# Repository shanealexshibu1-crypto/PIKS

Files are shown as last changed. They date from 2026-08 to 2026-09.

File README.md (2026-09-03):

# PIXS

Pixs is a 6 legged hexapod with 3-dof per leg i.e a hexapod with 18-dof. Custom made with a final volume box of 32 cm x 19.2 xm x 29.1 cm

## Printing Parts

Material used is PET-G

| Setting |  value |
| --- | ---: |
| **Nozzle** | **240°C** |
| **Bed** | **80°C** |
| **Part cooling** | **30–50%** |
| **Print speed** | **40–60 mm/s** |
| **First-layer nozzle** | **245°C** |
| **First-layer bed** | **80°C** |
| **Infill** | **10-15%** |

Do not print anything from the Assembly CAD section it is for reference only

## Assembly

1. Print 6 copies of Coxa Link 1_Part1, Coxa link 1_Part 2, Coxa Link 2_Part 1, Coxa Link 2_Part 2, Femur Part 1, Femur Part 2, Tibia, Servo Mount Coxa Bottom, Servo Mount Coxa Middle
   ,Servo Mount Coxa Top, Servo Mount Femur Bottom, Servo Mount Femur Middle,Servo Mount Femur Top, Servo Mount Tibia Bottom, Servo Mount Tibia Middle, Servo Mount Tibia Top.
   
2. Print 1 copy of Body Base and Body Top.

3. Insert One 606zz Ball Bearings into all 18 bottom of the servo mounts.

4. Then attach the Middle and top attachments of the Servo Mount. Secure this with 4pcs 45mm m3 Screw and heated inserts

5. Attach the Servo Horns that come with the Servo to all the servos.

6. Combine Coxa Link 1_Part 1 , Coxa Link 1_Part 2 and Coxa Servo Joint. Secure this with 3 pcs of m3 x 10mm screws and heated inserts.Repeat this 6 times.

7. Combine Coxa Link 2_Part 1, Coxa Link 2_Part 2 and Femur Servo Joint. Secure this with 3pcs of m3 x 10mm Screwa and heated inserts. Repeat this 6 times.

8. Combine the products from step 6 and step 7  using 5 pcs of m3x15mm Screws and heated inserts.Repeat this 6 times.

9. Attach the Femur Part 1 , femur Part 2, Tibia servo joint with m3 x 10mm screws and heated inserts.Repeat 6 times.

10. combine the femur with the product from step 8 with m3 x 10mm screws and heated inserts.Repeat 6 times.

11. finally cominbe the tibia and the product from step 10 with m3x10mm screws.Repeat 6 times.

12. Now you have finished 6 legs.

13. Next take the legs and secure them in the designated spots with m3 x 10 mm screws. Repeat this 6 times.

14. Then finish the design with the top plate with m3 x 10 mm screws and heated inserts.

15. Now u have a finished Assembled hexapod.

## Circuit Diagram

Screenshot 2026-09-01 at 8 35 06 PM

## Gallery

### One of the Finished Servo Mount

Screenshot 2026-09-01 at 5 22 45 PM

### Finished Leg Side View

Screenshot 2026-09-01 at 5 24 09 PM

### Base Plate(Body)

Screenshot 2026-09-01 at 5 28 04 PM

### Fully assembled Hexapod(Front View)

Screenshot 2026-09-01 at 5 33 56 PM

### Fully assembled Hexapod(Side View)

Screenshot 2026-09-01 at 5 34 15 PM

### Fully assembled Hexapod(Top View)

Screenshot 2026-09-01 at 5 34 48 PM

## Firmware 

### Features:

1. The firmware uses a tripod gait that follows the bezier curve.
2. Uses a 3rd party PS2 style controller to control the Hexapod, Left joystick for movement and right joystick for rotation and height adjustment.

### Installation

  1.Download the latest version of Arduino IDE
  
  2.Download the firmware from my github repo.
  
  3.Open the firmware with Arduino IDE.
  
  4.Connect the Arduino Mega to the laptop via Usb Cable.
  
  5.Finally, verify and upload the code to the Mega.
  
  6.Enjoy a fully working Hexapod.

## BOM

|Part Name |Qty|Pcs per Qty|Cost (AED)|Purchase Place|Purchase Link|
|---|---|---|---|---|---|
|Breadboard |1  |1 |2.68 |Ali Express |[Link](https://ar.aliexpress.com/item/1005009010052772.html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) |
|LiPo Battery |1  |1 |79.11 |Ali Express |[Link](https://ar.aliexpress.com/item/1005011908692707.html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) |
|M3 Screw 15mm |15 |10 |3.69 |Ali Express |[Link](https://ar.aliexpress.com/item/1005008693358029.html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) |
|M3 Screw 10mm |20 |10 |3.36 |Ali Express |[Link](https://ar.aliexpress.com/item/1005008693358029.html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) |
|Jumper Wires |1  |1 |12.39 |Ali Express |[Link](https://ar.aliexpress.com/item/1005012273851640.html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) |
|Capacitors 6.3 V (1000 uF)|1  |20 |9.7 |Ali Express |[Link](https://ar.aliexpress.com/item/1005006186858370.html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) |
|LED Toggle Switch |1  |1 |27.03 |Ali Express |[Link](https://ar.aliexpress.com/item/1005008856506094.html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) |
|Servo Extentions |1  |15 |26.42 |Ali Express |[Link](https://ar.aliexpress.com/item/1005010660995814.html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) |
|5V 15A Regulator |1  |1 |50.39 |Ali Express |[Link](https://ar.aliexpress.com/item/1005010218924050.html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) |
|DIN7991 M3 × 45mm Bolts |1  |50 |25.47 |Ali Express |[Link](https://ar.aliexpress.com/item/1005012615504199.html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) |
|DIN7991 M3 × 45mm Bolts |1  |50 |25.29 |Ali Express |[Link](https://ar.aliexpress.com/item/1005012779784744.html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) |
|PCA9685 Servo Driver |1  |2 |26.83 |Ali Express |[Link](https://ar.aliexpress.com/item/1005008717177681.html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) |
|Wireless Controller |1  |1 |42.2 |Ali Express |[Link](https://ar.aliexpress.com/item/1005012464305134.html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) |
|MEGA2560 R3 |1  |1 |61.57 |Ali Express |[Link](https://ar.aliexpress.com/item/1005008973924627.html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) |
|MG996 Servo |18 |1 |16.31 |Ali Express |[Link](https://ar.aliexpress.com/item/1005001878275044.html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) |
|Ball Bearing |2  |10 |28 |Ali Express |[Link](https://ar.aliexpress.com/item/560944845.html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) |
|Heated inserts |4  |100 |16.96 |Ali Express |[Link](https://ar.aliexpress.com/item/1005006201944599.html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) |
| | | | | | |
| | |TOTAL: |457.4 AED | | |

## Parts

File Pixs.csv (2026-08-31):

Part Name | Qty | Pcs per Qty | Cost (AED) | Purchase Place | Purchase Link
Breadboard | 1 | 1 | 2.68 | Ali Express | Link
LiPo Battery | 1 | 1 | 79.11 | Ali Express | Link
M3 Screw 15mm | 15 | 10 | 3.69 | Ali Express | Link
M3 Screw 10mm | 20 | 10 | 3.36 | Ali Express | Link
Jumper Wires | 1 | 1 | 12.39 | Ali Express | Link
Capacitors 6.3 V (1000 uF) | 1 | 20 | 9.7 | Ali Express | Link
LED Toggle Switch | 1 | 1 | 27.03 | Ali Express | Link
Servo Extentions | 1 | 15 | 26.42 | Ali Express | Link
5V 15A Regulator | 1 | 1 | 50.39 | Ali Express | Link
DIN7991 M3 × 45mm Bolts | 1 | 50 | 25.47 | Ali Express | Link
DIN7991 M3 × 45mm Bolts | 1 | 50 | 25.29 | Ali Express | Link
PCA9685 Servo Driver | 1 | 2 | 26.83 | Ali Express | Link
Wireless Controller | 1 | 1 | 42.2 | Ali Express | Link
MEGA2560 R3 | 1 | 1 | 61.57 | Ali Express | Link
MG996 Servo | 18 | 1 | 16.31 | Ali Express | Link
Ball Bearing | 2 | 10 | 28 | Ali Express | Link
Heated inserts | 4 | 100 | 16.96 | Ali Express | Link
 |  | TOTAL: | 457.4 AED

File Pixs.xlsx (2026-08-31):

Part Name | Qty | Pcs per Qty | Cost (AED) | Purchase Place | Purchase Link
Breadboard | 1 | 1 | 2.68 | Ali Express | Link (https://ar.aliexpress.com/item/1005009010052772.html?mp=1)
LiPo Battery | 1 | 1 | 79.11 | Ali Express | Link (https://ar.aliexpress.com/item/1005011908692707.html?mp=1)
M3 Screw 15mm | 15 | 10 | 3.69 | Ali Express | Link (https://ar.aliexpress.com/item/1005008693358029.html?mp=1)
M3 Screw 10mm | 20 | 10 | 3.36 | Ali Express | Link (https://ar.aliexpress.com/item/1005008693358029.html?mp=1)
Jumper Wires | 1 | 1 | 12.39 | Ali Express | Link (https://ar.aliexpress.com/item/1005012273851640.html?mp=1)
Capacitors 6.3 V (1000 uF) | 1 | 20 | 9.7 | Ali Express | Link (https://ar.aliexpress.com/item/1005006186858370.html?mp=1)
LED Toggle Switch | 1 | 1 | 27.03 | Ali Express | Link (https://ar.aliexpress.com/item/1005008856506094.html?mp=1)
Servo Extentions | 1 | 15 | 26.42 | Ali Express | Link (https://ar.aliexpress.com/item/1005010660995814.html?mp=1)
5V 15A Regulator | 1 | 1 | 50.39 | Ali Express | Link (https://ar.aliexpress.com/item/1005010218924050.html?mp=1)
DIN7991 M3 × 45mm Bolts | 1 | 50 | 25.47 | Ali Express | Link (https://ar.aliexpress.com/item/1005012615504199.html?mp=1)
DIN7991 M3 × 45mm Bolts | 1 | 50 | 25.29 | Ali Express | Link (https://ar.aliexpress.com/item/1005012779784744.html?mp=1)
PCA9685 Servo Driver | 1 | 2 | 26.83 | Ali Express | Link (https://ar.aliexpress.com/item/1005008717177681.html?mp=1)
Wireless Controller | 1 | 1 | 42.2 | Ali Express | Link (https://ar.aliexpress.com/item/1005012464305134.html?mp=1)
MEGA2560 R3 | 1 | 1 | 61.57 | Ali Express | Link (https://ar.aliexpress.com/item/1005008973924627.html?mp=1)
MG996 Servo | 18 | 1 | 16.31 | Ali Express | Link (https://ar.aliexpress.com/item/1005001878275044.html?mp=1)
Ball Bearing | 2 | 10 | 28 | Ali Express | Link (https://ar.aliexpress.com/item/560944845.html?curPageLogUid=WHP7pWYI5Soi)
Heated inserts | 4 | 100 | 16.96 | Ali Express | Link (https://ar.aliexpress.com/item/1005006201944599.html?mp=1)
 |  | TOTAL: | 457.4 AED

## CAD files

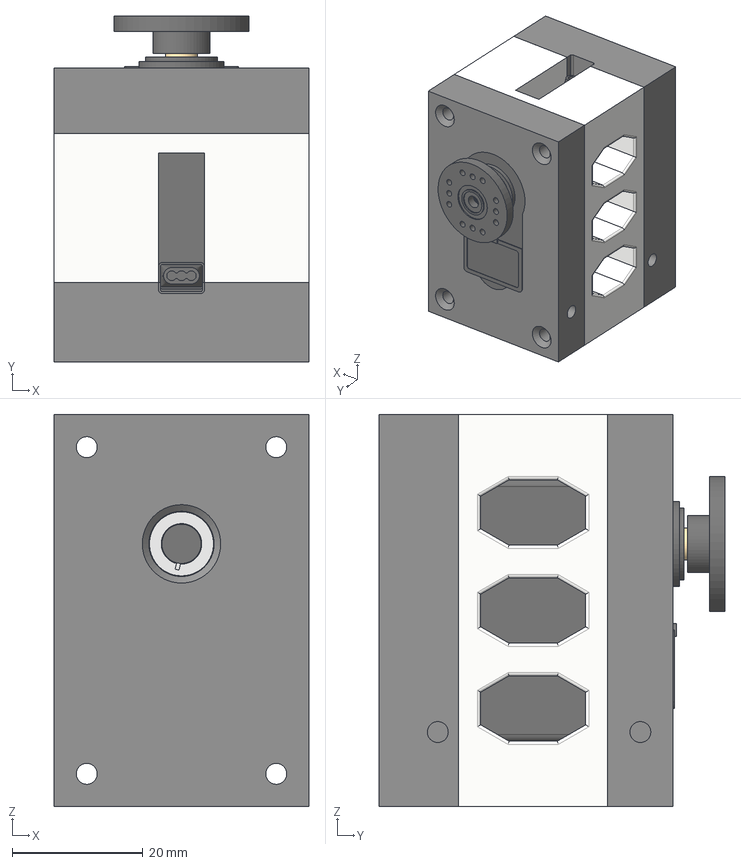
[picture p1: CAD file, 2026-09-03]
CAD/Assembly/Coxa Joint Assembly/Coxa Joint Assembly.step
39.0 x 53.0 x 60.0 mm
Servo+MG996R
attachmentCircular
attachmentCircular--1

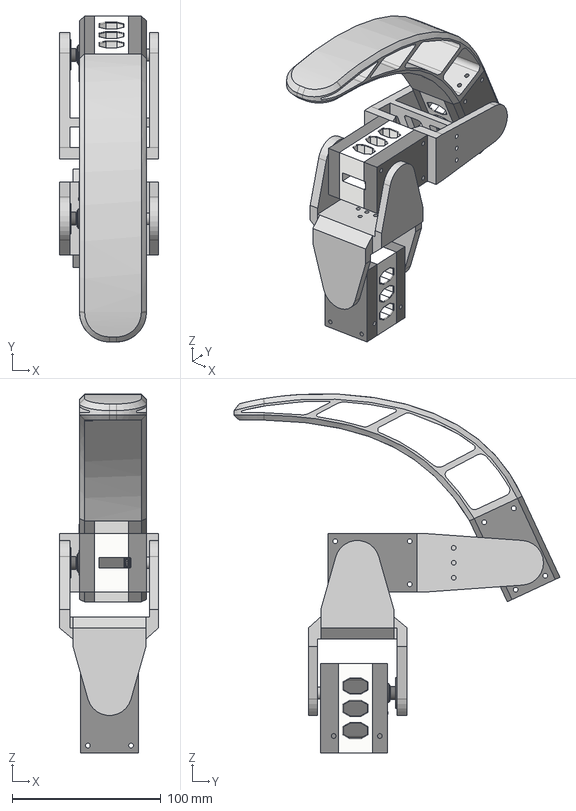
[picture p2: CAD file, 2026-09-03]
CAD/Assembly/Leg/Leg.step
66.4 x 218.8 x 241.0 mm
Servo+MG996R x 3
attachmentCircular x 3
attachmentCircular--1 x 3
Femur(1)
Femur(2)

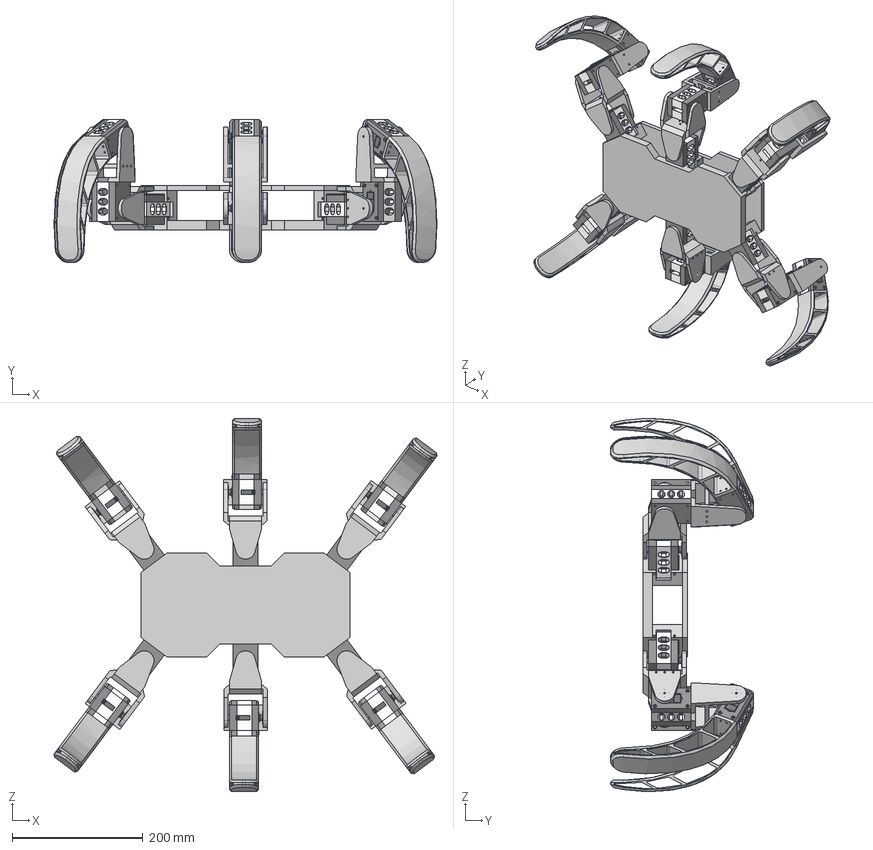
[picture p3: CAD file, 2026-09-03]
CAD/Assembly/PIKS/PIKS.step
587.0 x 218.8 x 572.3 mm
body new
top plate new
Servo+MG996R x 18
attachmentCircular x 18
attachmentCircular--1 x 18
Femur(1) x 6
Femur(2) x 6

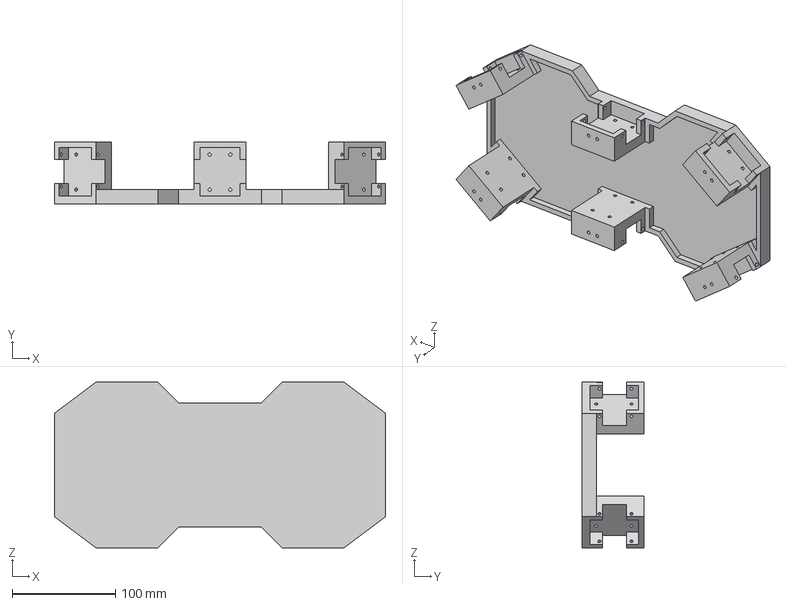
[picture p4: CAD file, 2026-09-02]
CAD/Body/Base/Body Base.step
320.0 x 60.2 x 160.0 mm

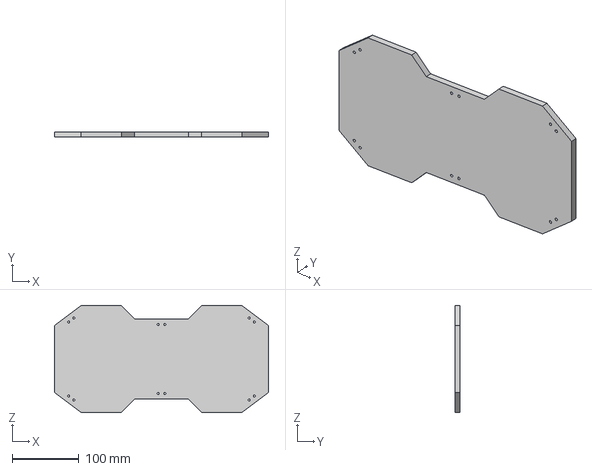
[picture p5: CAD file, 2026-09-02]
CAD/Body/Top/Body Top.step
320.0 x 7.75 x 160.0 mm

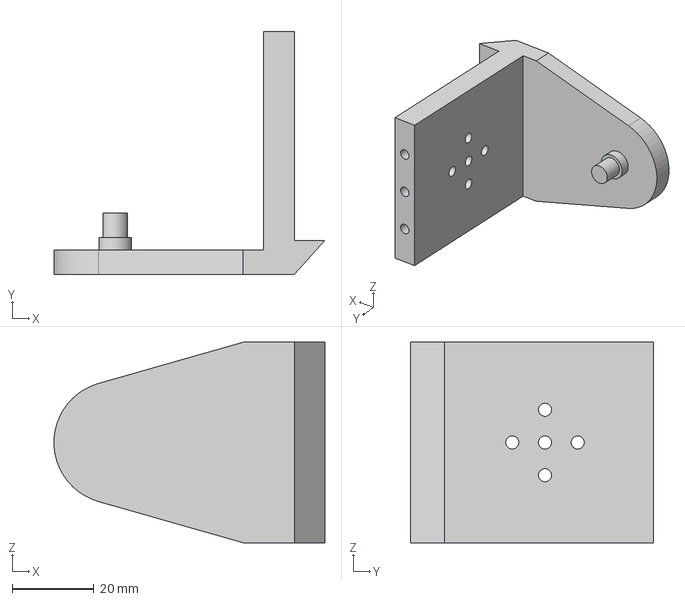
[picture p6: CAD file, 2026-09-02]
CAD/Coxa/Link 1/Part 1/Coxa Link 1_Part 1.step
66.2 x 59.4 x 49.0 mm

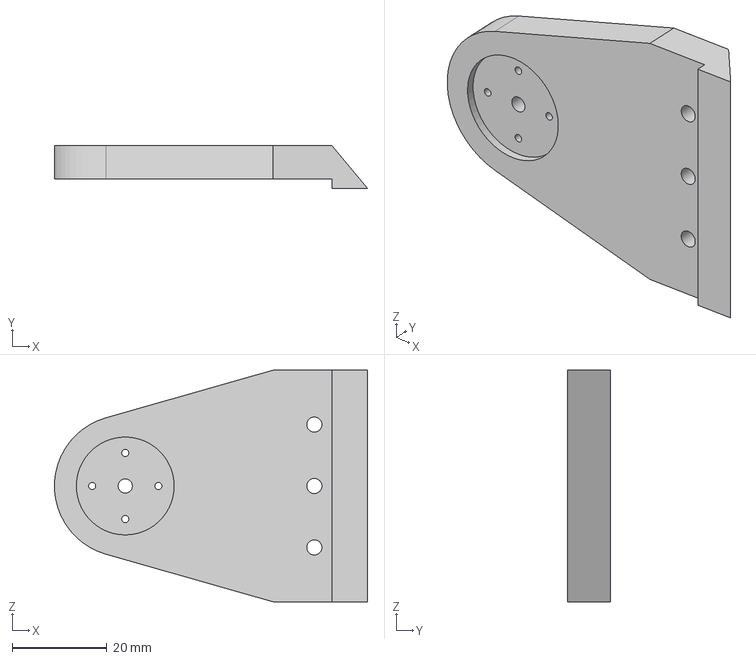
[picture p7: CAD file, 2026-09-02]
CAD/Coxa/Link 1/Part 2/Coxa Link 1_Part 2.step
66.2 x 9.00 x 49.0 mm

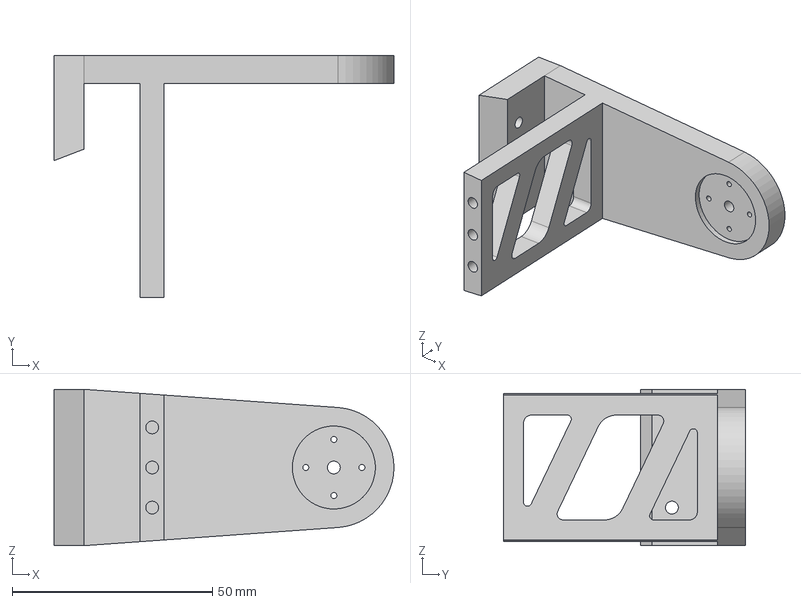
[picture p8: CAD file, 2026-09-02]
CAD/Femur/Part 1/Femur 1.step
84.8 x 60.4 x 39.0 mm

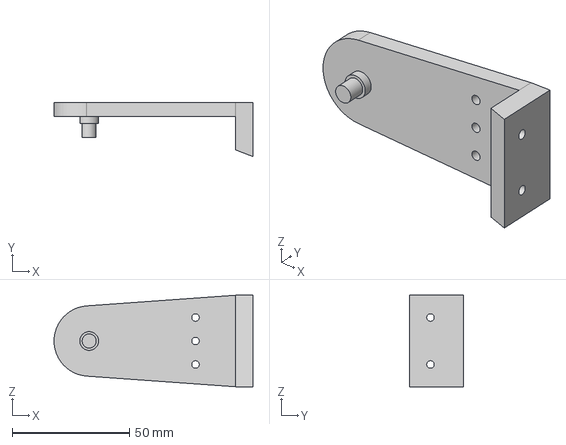
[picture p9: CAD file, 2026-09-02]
CAD/Femur/Part 2/Femur 2.step
84.8 x 23.1 x 39.0 mm

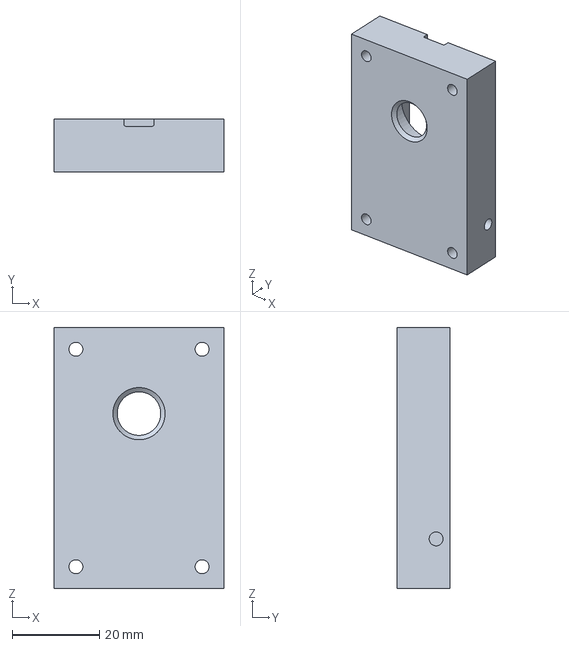
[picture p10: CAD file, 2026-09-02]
CAD/Servo Mounts/Coxa/Bottom/Servo Mount Coxa Bottom.step
39.0 x 12.2 x 60.0 mm

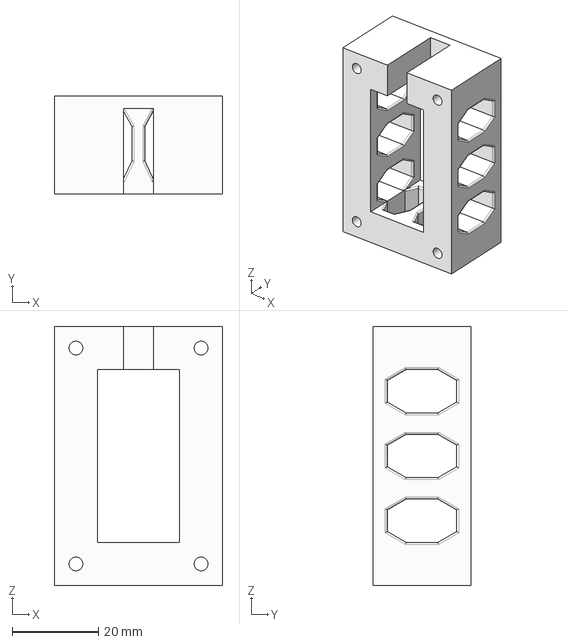
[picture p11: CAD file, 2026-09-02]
CAD/Servo Mounts/Coxa/Middle/Servo Mount Coxa Middle.step
39.0 x 22.8 x 60.0 mm

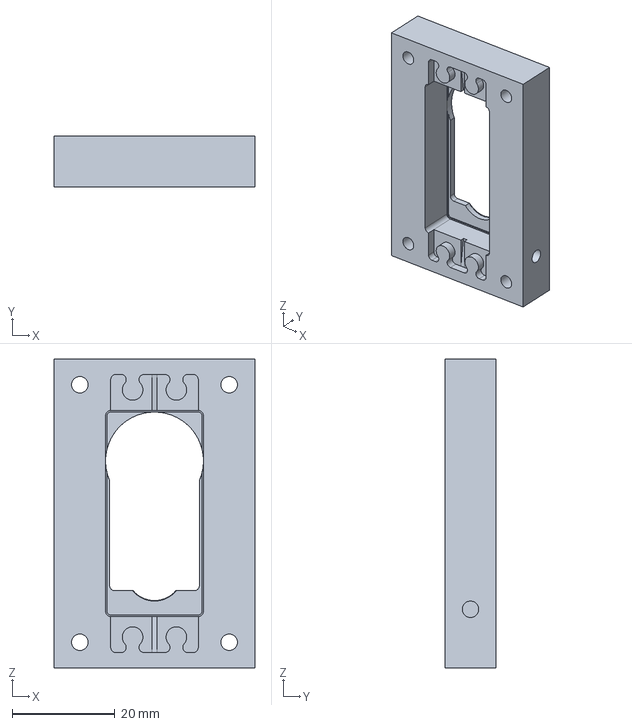
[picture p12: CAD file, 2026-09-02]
CAD/Servo Mounts/Coxa/Top/Servo Mount Coxa Top.step
39.0 x 10.00 x 60.0 mm

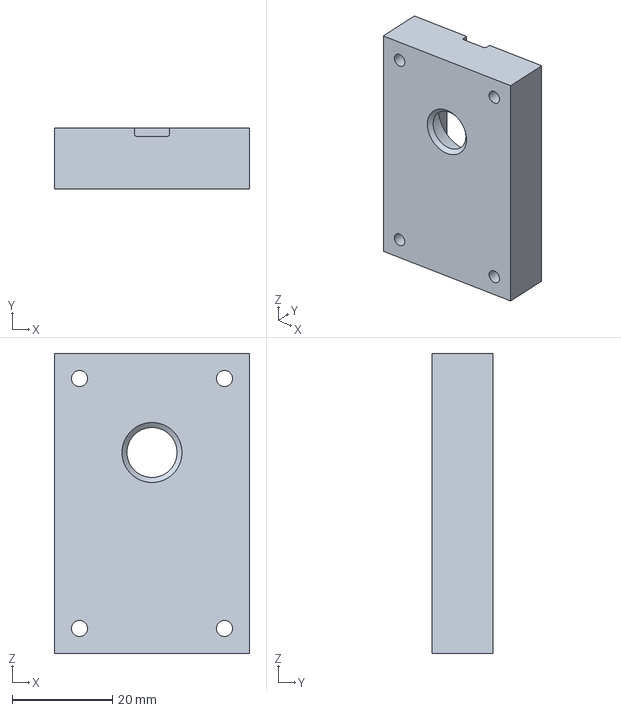
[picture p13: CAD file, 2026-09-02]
CAD/Servo Mounts/Femur/Bottom/Servo Mount Femur Bottom.step
39.0 x 12.2 x 60.0 mm

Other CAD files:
CAD/Assembly/Femur Joint Assembly/Femur Joint Assembly.step
CAD/Assembly/Tibia Joint Assembly/Tibia Joint Assembled.step
CAD/Coxa/Link 2/Part 1/Coxa Link 2_Part 1.step
CAD/Coxa/Link 2/Part 2/Coxa Link 2_Part 2.step
CAD/Servo Mounts/Femur/Middle/Servo Mount Femur Middle.step
CAD/Assembly/Coxa Joint Assembly/Coxa Joint Assembly.f3z
CAD/Assembly/Coxa Joint Assembly/Coxa Joint Assembly.stl
CAD/Assembly/Femur Joint Assembly/Femur Joint Assembly.f3z
CAD/Assembly/Femur Joint Assembly/Femur Joint Assembly.stl
CAD/Assembly/Leg/Leg.f3z
CAD/Assembly/Leg/Leg.stl
CAD/Assembly/PIKS/PIKS.f3z
CAD/Assembly/Tibia Joint Assembly/Tibia Joint Assembled.f3z
CAD/Assembly/Tibia Joint Assembly/Tibia Joint Assembled.stl
CAD/Body/Base/Body Base.f3d
CAD/Body/Base/Body Base.stl
CAD/Body/Top/Body Top.f3d
CAD/Body/Top/Body Top.stl
CAD/Coxa/Link 1/Part 1/Coxa Link 1_Part 1.f3z
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

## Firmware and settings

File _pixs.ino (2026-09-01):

#include <Wire.h>
#include <Adafruit_PWMServoDriver.h>
#include <PS2X_lib.h>
#include <math.h>

Adafruit_PWMServoDriver leftDriver  = Adafruit_PWMServoDriver(0x40);
Adafruit_PWMServoDriver rightDriver = Adafruit_PWMServoDriver(0x41);

PS2X ps2x;

#define PS2_DAT 22
#define PS2_CMD 23
#define PS2_ATT 24
#define PS2_CLK 25

int ps2Error = 0;

const float COXA_LENGTH  = 87.5;
const float FEMUR_LENGTH = 110.0;
const float TIBIA_LENGTH = 220.0;

#define SERVO_FREQ 50

const int SERVO_MIN_US = 500;
const int SERVO_MAX_US = 2500;

enum LegID
{
    LF = 0,
    LM = 1,
    LR = 2,
    RF = 3,
    RM = 4,
    RR = 5
};

enum JointID
{
    COXA = 0,
    FEMUR = 1,
    TIBIA = 2
};

struct ServoCalibration
{
    float center;
    float offset;
    int direction;
    float minAngle;
    float maxAngle;
};

ServoCalibration LF_Coxa  = {90, 0, +1, 5, 175};
ServoCalibration LF_Femur = {90, 0, +1, 5, 175};
ServoCalibration LF_Tibia = {115, 0, +1, 5, 175};

ServoCalibration LM_Coxa  = {90, 0, +1, 5, 175};
ServoCalibration LM_Femur = {90, 0, +1, 5, 175};
ServoCalibration LM_Tibia = {115, 0, +1, 5, 175};

ServoCalibration LR_Coxa  = {90, 0, +1, 5, 175};
ServoCalibration LR_Femur = {90, 0, +1, 5, 175};
ServoCalibration LR_Tibia = {115, 0, +1, 5, 175};


ServoCalibration RF_Coxa  = {90, 0, -1, 5, 175};
ServoCalibration RF_Femur = {90, 0, -1, 5, 175};
ServoCalibration RF_Tibia = {115, 0, -1, 5, 175};

ServoCalibration RM_Coxa  = {90, 0, -1, 5, 175};
ServoCalibration RM_Femur = {90, 0, -1, 5, 175};
ServoCalibration RM_Tibia = {115, 0, -1, 5, 175};

ServoCalibration RR_Coxa  = {90, 0, -1, 5, 175};
ServoCalibration RR_Femur = {90, 0, -1, 5, 175};
ServoCalibration RR_Tibia = {115, 0, -1, 5, 175};

struct LegPosition
{
    float x;
    float y;
    float z;
};

LegPosition foot[6];

const float STAND_X_FRONT = 150.0;
const float STAND_X_MIDDLE = 0.0;
const float STAND_X_REAR = -150.0;

const float STAND_Y = 145.0;

float bodyHeight = -170.0;

float moveX = 0;
float moveY = 0;
float rotation = 0;


const float MAX_FORWARD = 80.0;
const float MAX_STRAFE  = 60.0;
const float MAX_ROTATE  = 45.0;

const unsigned long GAIT_PERIOD = 700;

const float STEP_HEIGHT = 55.0;

float cubicBezier(float p0, float p1, float p2, float p3, float t)
{
    float u = 1.0 - t;

    return
        (u * u * u * p0) +
        (3.0 * u * u * t * p1) +
        (3.0 * u * t * t * p2) +
        (t * t * t * p3);
}

uint16_t microsecondsToTicks(int us)
{
    
    return (uint16_t)((us * 4096.0) / 20000.0);
}


void writeServoPWM(bool rightSide, int channel, float angle)
{
    angle = constrain(angle, 0, 180);

    int pulse =
        SERVO_MIN_US +
        ((SERVO_MAX_US - SERVO_MIN_US) * angle / 180.0);

    uint16_t ticks = microsecondsToTicks(pulse);

    if (rightSide)
        rightDriver.setPWM(channel, 0, ticks);
    else
        leftDriver.setPWM(channel, 0, ticks);
}

float calibratedAngle(ServoCalibration &servo, float ikAngle)
{
    float result =
        servo.center +
        servo.offset +
        servo.direction * ikAngle;

    result = constrain(
        result,
        servo.minAngle,
        servo.maxAngle
    );

    return result;
}

ServoCalibration* getCalibration(int leg, int joint)
{
    if (leg == LF)
    {
        if (joint == COXA)  return &LF_Coxa;
        if (joint == FEMUR) return &LF_Femur;
        return &LF_Tibia;
    }

    if (leg == LM)
    {
        if (joint == COXA)  return &LM_Coxa;
        if (joint == FEMUR) return &LM_Femur;
        return &LM_Tibia;
    }

    if (leg == LR)
    {
        if (joint == COXA)  return &LR_Coxa;
        if (joint == FEMUR) return &LR_Femur;
        return &LR_Tibia;
    }

    if (leg == RF)
    {
        if (joint == COXA)  return &RF_Coxa;
        if (joint == FEMUR) return &RF_Femur;
        return &RF_Tibia;
    }

    if (leg == RM)
    {
        if (joint == COXA)  return &RM_Coxa;
        if (joint == FEMUR) return &RM_Femur;
        return &RM_Tibia;
    }

    // RR
    if (joint == COXA)  return &RR_Coxa;
    if (joint == FEMUR) return &RR_Femur;
    return &RR_Tibia;
}

int getServoChannel(int leg, int joint)
{
    if (leg <= LR)
    {
        // LEFT
        return leg * 3 + joint;
    }
    else
    {
        // RIGHT
        return (leg - 3) * 3 + joint;
    }
}

bool solveIK(
    float x,
    float y,
    float z,
    float &coxaAngle,
    float &femurAngle,
    float &tibiaAngle
)
{
    coxaAngle = atan2(y, x) * 180.0 / PI;

    float horizontal =
        sqrt((x * x) + (y * y));

    float r =
        horizontal - COXA_LENGTH;


    float distance =
        sqrt((r * r) + (z * z));



    if (distance > FEMUR_LENGTH + TIBIA_LENGTH)
        return false;

    if (distance < fabs(FEMUR_LENGTH - TIBIA_LENGTH))
        return false;


    float cosTibia =
        (
            (FEMUR_LENGTH * FEMUR_LENGTH) +
            (TIBIA_LENGTH * TIBIA_LENGTH) -
            (distance * distance)
        )
        /
        (
            2.0 *
            FEMUR_LENGTH *
            TIBIA_LENGTH
        );

    cosTibia = constrain(cosTibia, -1.0, 1.0);

    float tibiaRad =
        acos(cosTibia);

    tibiaAngle =
        tibiaRad * 180.0 / PI;

    float angleToFoot =
        atan2(z, r);

    float cosFemur =
        (
            (FEMUR_LENGTH * FEMUR_LENGTH) +
            (distance * distance) -
            (TIBIA_LENGTH * TIBIA_LENGTH)
        )
        /
        (
            2.0 *
            FEMUR_LENGTH *
            distance
        );

    cosFemur = constrain(cosFemur, -1.0, 1.0);

    float triangleAngle =
        acos(cosFemur);

    float femurRad =
        angleToFoot + triangleAngle;

    femurAngle =
        femurRad * 180.0 / PI;

    coxaAngle += 90.0;

    femurAngle = 90.0 - femurAngle;

    tibiaAngle = tibiaAngle;


    return true;
}

void moveLeg(
    int leg,
    float x,
    float y,
    float z
)
{
    float coxa;
    float femur;
    float tibia;

    bool valid =
        solveIK(
            x,
            y,
            z,
            coxa,
            femur,
            tibia
        );

    if (!valid)
        return;


    ServoCalibration *sCoxa =
        getCalibration(leg, COXA);

    ServoCalibration *sFemur =
        getCalibration(leg, FEMUR);

    ServoCalibration *sTibia =
        getCalibration(leg, TIBIA);


    float servoCoxa =
        calibratedAngle(*sCoxa, coxa);

    float servoFemur =
        calibratedAngle(*sFemur, femur);

    float servoTibia =
        calibratedAngle(*sTibia, tibia);


    bool rightSide =
        (leg >= RF);

    int channelCoxa =
        getServoChannel(leg, COXA);

    int channelFemur =
        getServoChannel(leg, FEMUR);

    int channelTibia =
        getServoChannel(leg, TIBIA);


    writeServoPWM(
        rightSide,
        channelCoxa,
        servoCoxa
    );

    writeServoPWM(
        rightSide,
        channelFemur,
        servoFemur
    );

    writeServoPWM(
        rightSide,
        channelTibia,
        servoTibia
    );
}

void calculateStandPositions()
{
    
    foot[LF] = {
        STAND_X_FRONT,
        +STAND_Y,
        bodyHeight
    };

    foot[LM] = {
        STAND_X_MIDDLE,
        +STAND_Y,
        bodyHeight
    };

    foot[LR] = {
        STAND_X_REAR,
        +STAND_Y,
        bodyHeight
    };

    foot[RF] = {
        STAND_X_FRONT,
        -STAND_Y,
        bodyHeight
    };

    foot[RM] = {
        STAND_X_MIDDLE,
        -STAND_Y,
        bodyHeight
    };

    foot[RR] = {
        STAND_X_REAR,
        -STAND_Y,
        bodyHeight
    };
}



void stand()
{
    calculateStandPositions();

    for (int leg = 0; leg < 6; leg++)
    {
        moveLeg(
            leg,
            foot[leg].x,
            foot[leg].y,
            foot[leg].z
        );
    }
}

bool isTripodA(int leg)
{
    return
        leg == LF ||
        leg == RM ||
        leg == LR;
}

void applyRotation(
    float x,
    float y,
    float rotationAmount,
    float &outX,
    float &outY
)
{
    float rot =
        rotationAmount * PI / 180.0;

    outX =
        x * cos(rot) -
        y * sin(rot);

    outY =
        x * sin(rot) +
        y * cos(rot);
}

void updateGait()
{
    unsigned long now = millis();

    float cycle =
        (now % GAIT_PERIOD) /
        (float)GAIT_PERIOD;

    float stepX =
        moveX;

    float stepY =
        moveY;

    for (int leg = 0; leg < 6; leg++)
    {
        bool tripodA =
            isTripodA(leg);

        float phase =
            cycle;

        if (!tripodA)
            phase += 0.5;

        if (phase >= 1.0)
            phase -= 1.0;


        float x =
            foot[leg].x;

        float y =
            foot[leg].y;

        float z =
            foot[leg].z;

        if (phase < 0.5)
        {
            float t =
                phase / 0.5;

            float startX =
                x - stepX * 0.5;

            float endX =
                x + stepX * 0.5;


            float startY =
                y - stepY * 0.5;

            float endY =
                y + stepY * 0.5;


            float control1X =
                startX + stepX * 0.25;

            float control2X =
                endX - stepX * 0.25;


            float control1Y =
                startY + stepY * 0.25;

            float control2Y =
                endY - stepY * 0.25;


            float targetX =
                cubicBezier(
                    startX,
                    control1X,
                    control2X,
                    endX,
                    t
                );

            float targetY =
                cubicBezier(
                    startY,
                    control1Y,
                    control2Y,
                    endY,
                    t
                );


            float targetZ =
                cubicBezier(
                    z,
                    z - STEP_HEIGHT,
                    z - STEP_HEIGHT,
                    z,
                    t
                );


            float rotatedX;
            float rotatedY;

            applyRotation(
                targetX,
                targetY,
                rotation,
                rotatedX,
                rotatedY
            );


            moveLeg(
                leg,
                rotatedX,
                rotatedY,
                targetZ
            );
        }

        else
        {
            float t =
                (phase - 0.5) / 0.5;

            float targetX =
                x + stepX * 0.5 -
                stepX * t;

            float targetY =
                y + stepY * 0.5 -
                stepY * t;


            float rotatedX;
            float rotatedY;

            applyRotation(
                targetX,
                targetY,
                rotation,
                rotatedX,
                rotatedY
            );


            moveLeg(
                leg,
                rotatedX,
                rotatedY,
                z
            );
        }
    }
}

int applyDeadzone(
    int value,
    int deadzone
)
{
    if (abs(value) < deadzone)
        return 0;

    return value;
}

float stickToFloat(
    int value,
    float maximum
)
{
    value -= 128;

    value =
        applyDeadzone(
            value,
            15
        );

    if (value == 0)
        return 0;

    float normalized =
        value / 127.0;

    return normalized * maximum;
}

void readController()
{
    ps2x.read_gamepad(
        false,
        0
    );

    int leftX =
        ps2x.Analog(PSS_LX);

    int leftY =
        ps2x.Analog(PSS_LY);

    int rightX =
        ps2x.Analog(PSS_RX);

    int rightY =
        ps2x.Analog(PSS_RY);

    moveY =
        -stickToFloat(
            leftX,
            MAX_STRAFE
        );

    moveX =
        -stickToFloat(
            leftY,
            MAX_FORWARD
        );

    rotation =
        -stickToFloat(
            rightX,
            MAX_ROTATE
        );

    float heightChange =
        stickToFloat(
            rightY,
            1.0
        );


    bodyHeight +=
        heightChange * 3.0;


    bodyHeight =
        constrain(
            bodyHeight,
            -220.0,
            -120.0
        );


    static bool lastStart = false;

    bool startPressed =
        ps2x.ButtonPressed(PSB_START);

    if (startPressed && !lastStart)
    {
        stand();
    }

    lastStart =
        startPressed;
}


void setupPS2()
{
    delay(300);

    ps2Error =
        ps2x.config_gamepad(
            PS2_CLK,
            PS2_CMD,
            PS2_ATT,
            PS2_DAT,
            false,
            false
        );

    if (ps2Error == 0)
    {
        Serial.println(
            "PS2 controller connected."
        );
    }
    else
    {
        Serial.print(
            "PS2 controller error: "
        );

        Serial.println(ps2Error);
    }
}


void setup()
{
    Serial.begin(115200);

    Wire.begin();

    leftDriver.begin();
    rightDriver.begin();

    leftDriver.setOscillatorFrequency(27000000);
    rightDriver.setOscillatorFrequency(27000000);

    leftDriver.setPWMFreq(SERVO_FREQ);
    rightDriver.setPWMFreq(SERVO_FREQ);


    delay(500);


    setupPS2();

    calculateStandPositions();


    stand();


    Serial.println(
        "HEXAPOD READY"
    );
}

void loop()
{
    readController();

    updateGait();

    delay(15);
}

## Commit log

2026-09-02 Femur Part 1
    [Femur 1.f3d, Femur 1.step, Femur 1.stl]
2026-09-02 Femur Part 2
    [Femur 2.f3d, Femur 2.step, Femur 2.stl]
2026-09-02 Coxa Link 1 Part 1
    [Coxa Link 1_Part 1.f3z, Coxa Link 1_Part 1.step, Coxa Link 1_Part 1.stl]
2026-09-02 Coxa Link 2 Part 1
    [Coxa Link 2_Part 1.f3z, Coxa Link 2_Part 1.step, Coxa Link 2_Part 1.stl]
2026-09-02 Coxa Link 1 Part 2
    [Coxa Link 1_Part 2.f3z, Coxa Link 1_Part 2.step, Coxa Link 1_Part 2.stl]
2026-09-02 Coxa Link 2 Part 2
    [Coxa Link 2_Part 2.f3z, Coxa Link 2_Part 2.step, Coxa Link 2_Part 2.stl]
2026-09-02 Coxa Joint Bottom
    [Servo Mount Coxa Bottom.f3z, Servo Mount Coxa Bottom.step, Servo Mount Coxa Bottom.stl]
2026-09-02 Coxa Joint Middle
    [Servo Mount Coxa Middle.f3z, Servo Mount Coxa Middle.step, Servo Mount Coxa Middle.stl]
2026-09-02 Coxa Join Top
    [Servo Mount Coxa Top.f3z, Servo Mount Coxa Top.step, Servo Mount Coxa Top.stl]
